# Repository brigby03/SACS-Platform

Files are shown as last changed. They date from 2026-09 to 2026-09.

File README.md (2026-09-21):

# SACS — Spacecraft Attitude Control Simulator

SACS is a single-axis, nearly frictionless spacecraft attitude-control testbed developed during Cal Poly's 2024 Summer Undergraduate Research Program (SURP). The platform rotates about its vertical $z$-axis on an air spindle and uses paired cold-gas thrusters to perform yaw maneuvers.

This repository contains the embedded control software and MATLAB/Simulink models used to simulate, command, and validate the platform.

> SACS is the original **single-axis SURP platform**. It is distinct from SADS, the three-axis spherical-air-bearing platform.

## Project goals

SACS was developed to:

- Create a low-complexity, low-friction physical analog of single-axis spacecraft rotation.
- Implement closed-loop yaw control using cold-gas thrusters.
- Compare predicted MATLAB/Simulink behavior with experimental results.
- Provide a testbed for control-law tuning and pulse-modulated actuator logic.

## System overview

The platform is built on an aluminum-extrusion frame supported by a porous-carbon air spindle. A compressed-gas supply feeds solenoid valves connected to opposing nozzle pairs. The nozzles are mounted at a moment arm from the center of rotation so that each pair produces positive or negative torque about the $z$-axis.

A BNO085 IMU measures platform yaw and angular rate. The embedded controller compares these measurements with the target state, calculates a desired torque using a PD control law, and converts the continuous command into discrete thruster firings.

```mermaid
flowchart TD
    TARGET["Target yaw and yaw rate"] --> PD["PD controller"]
    IMU["BNO085 yaw and gyro-Z"] --> PD
    PD --> LIMIT["Torque limit and thrust conversion"]
    LIMIT --> FILTER["First-order filter"]
    FILTER --> RELAY["Schmitt-trigger logic"]
    RELAY --> VALVES["Solenoid valves and cold-gas thrusters"]
    VALVES --> PLATFORM["Single-axis air-spindle platform"]
    PLATFORM --> IMU
```

## Control system

### PD attitude controller

The controller uses yaw-angle error and yaw-rate error:

$$
u = K_p(\theta_d-\theta) + K_d(\dot{\theta}_d-\dot{\theta}),
$$

where $u$ is the requested control torque. The gains can be selected from the desired natural frequency $\omega_n$, damping ratio $\zeta$, and estimated platform inertia $I_{zz}$:

$$
K_p = I_{zz}\omega_n^2,
\qquad
K_d = 2\zeta\omega_n I_{zz}.
$$

The requested torque is limited to the torque available from the thrusters and converted into the equivalent force required from each nozzle.

### Thruster modulation

Because the solenoid valves are on/off actuators, they cannot directly produce the continuous thrust requested by the PD controller. The embedded software therefore applies:

1. A first-order filter to the magnitude of the desired thrust.
2. A Schmitt trigger with separate on and off thresholds to provide hysteresis.
3. Sign logic to select the positive- or negative-torque thruster pair.

This PWPF-style approach reduces rapid valve switching while approximating a continuous control command with discrete pulses. This reduces fuel use while maintaining pointing within predefined thresholds.

### Operator controls

An IR remote is used to:

- Enable or disable closed-loop thruster firing [Power Button].
- Increment or decrement $K_p$ and $K_d$ [Volume +/-].
- Adjust the target yaw angle [see code].
- Adjust the target yaw rate [see code].

## Hardware represented by the software

| Component | Function |
| --- | --- |
| Single-axis air spindle | Provides nearly frictionless rotation about the vertical axis |
| Aluminum-extrusion platform | Supports the avionics, gas system, and thruster moment arms |
| Compressed-gas supply | Supplies the cold-gas propulsion system |
| Opposing nozzle pairs | Apply positive or negative yaw torque |
| Solenoid valves | Switch the thrusters on and off |
| BNO085 IMU | Measures yaw angle and angular velocity about $z$ |
| Embedded controller | Runs the feedback and thruster-modulation logic |
| IR receiver and remote | Enables the system and supports live tuning |

## Repository contents

| File | Description |
| --- | --- |
| `SACS_CS_1.3.ino` | Embedded PD controller, BNO085 interface, IR-remote input, filtering, and Schmitt-trigger thruster logic |
| `ControlledMotion.slx` | Simulink model of the closed-loop platform dynamics and pulsed-thruster controller |
| `ControlledMotionScript.m` | Defines controlled-motion parameters, runs the model, and plots attitude, body rate, and torque |
| `TorqueFreeMotion.slx` | Simulink model of rotational motion used to evaluate the platform dynamics |
| `TorqueFreeMotionScript.m` | Defines the inertia, applied torque, and initial conditions for the torque-free-motion model |

## Software requirements

### Embedded controller

- Arduino IDE or a compatible build environment
- [SparkFun BNO080/BNO085 Arduino Library](https://github.com/sparkfun/SparkFun_BNO080_Arduino_Library)
- [Arduino-IRremote](https://github.com/Arduino-IRremote/Arduino-IRremote)

The current sketch expects:

- BNO085 I²C address: `0x4A`
- I²C clock: `400 kHz`
- IMU update period: `50 ms`
- Positive- and negative-torque solenoid outputs: pins `3` and `4`
- IR receiver input: pin `15`
- Serial baud rate: `115200`

Confirm the target board, pin mapping, valve-driver polarity, and electrical interface before uploading the sketch.

### Simulation

- MATLAB
- Simulink
- Stateflow

The models were saved using MATLAB/Simulink R2024a. Compatibility with earlier releases is not guaranteed.

## Running the simulations

Place each script in the same directory as its corresponding Simulink model.

### Controlled motion

Open MATLAB in the repository directory and run:

```matlab
ControlledMotionScript
```

The script sets the inertia, initial attitude and body rate, controller gains, Schmitt-trigger thresholds, thruster torque, and simulation duration. It then runs `ControlledMotion.slx` and plots:

- Yaw angle versus time
- Angular velocity versus time
- Desired and commanded torque versus time

### Rotational dynamics

Run:

```matlab
TorqueFreeMotionScript
```

This initializes the inertia matrix, applied torque, initial angular velocity, and simulation duration before running `TorqueFreeMotion.slx`.

## Running the physical platform via cold gas thrusters.

1. Place the platform onto a flat and level surface.
2. Place the paintball canister into the sleeve in the center of the platform and attach it's output hose to the thruster manifold. Be sure not to open the valve on the paintball canister until immediately prior to running a control test.
3. Ensure that the air compressor is powered and connected to the inlet of the Air Spindle, and flip the lever to turn on the air compressor. This will allow the platform to freely spin. The air compressor will fill to ~120psi and then shut off until it falls to ~90psi, and then refill until powered off.
4. Verify that the platform is balanced and free to rotate without cable interference. In the somewhat likely event of an unbalanced platform, you can shim the four corners with thin microfiber towels and check  the proper orientation of the platform with a levels.
5. Open the valve of the paintball canister to allow pressurized air into the thruster manifold.
6. Press the IR-remote power button to enable once the paintball canister's valve has been opened and the platform is freely spinning. The power button can be used to enable/disable control at any time for convenience of testing/demonstration.
7. Once the test is complete, disable control via the power button on the IR-remote to stop the valves from opening.
8. Once the platform is settled to a stop, close the valve on the paintball canister, and then re-enable thruster control one last time in order to purge the lines of any remaining pressurized air.
9. Once the lines have been purged, the paintball canister can be removed and the platform can be stowed.

## Experimental validation

The Simulink model was used to predict the controlled yaw response and compare it with the physical platform. Repeated large-angle maneuver tests settled in roughly **14–15 seconds**, closely matching the simulated response. Differences between the model and experiment were attributed primarily to uncertainty in delivered thrust and unmodeled friction.

## Safety

This project operates pressurized gas, electrically actuated valves, and a freely rotating structure.

- Wear eye protection during pressurized testing.
- Keep people and loose objects outside the platform's swept area.
- Never provide power to the valves while hands or tools are near a nozzle or moving structure.
- Always keep the paintball canister's valve closed until undergoing pressurized testing to avoid unexpected mishaps with the valves.
- Depressurize the system before changing pneumatic connections.
- Provide accessible electrical and pneumatic emergency shutoffs.

## Academic context

SACS was originally developed by **Bricen Rigby** through the 2024 Summer Undergraduate Research Program in the Aerospace Engineering Department at California Polytechnic State University, San Luis Obispo, under the guidance of **Professor Eric Mehiel**. It has since been used in multiple theses related to spacecraft attitude control simulation and testing for its utility in sensor, actuator, and control system validation.

## License

No license has been selected. Until a license is added, the source is not automatically licensed for reuse, modification, or redistribution.

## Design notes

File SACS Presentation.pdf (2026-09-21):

# Spacecraft Attitude

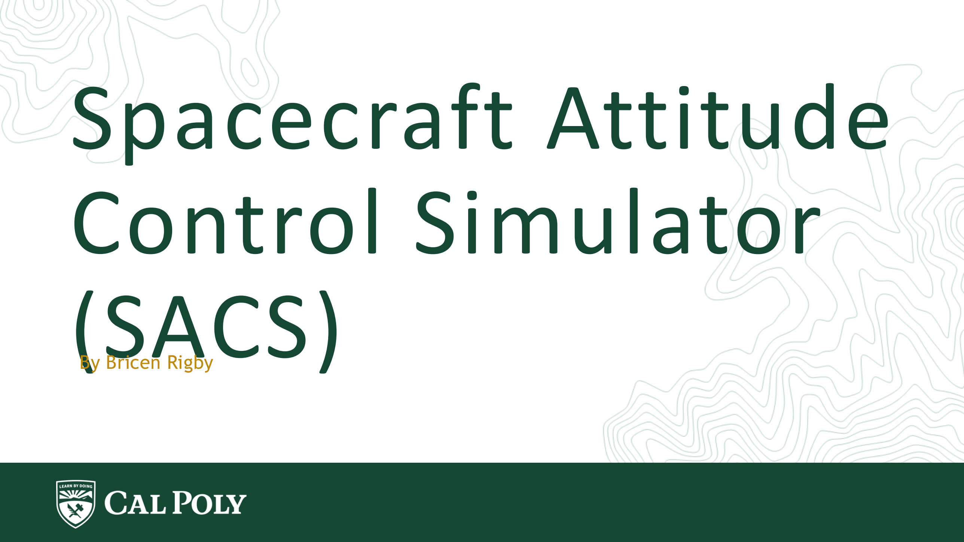
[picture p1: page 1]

# Control Simulator

(SACS) By Bricen Rigby

# Project Overview

## Objective:

## Develop a single-axis attitude control simulator to replicate the frictionless environment of space and test cold gas thruster control

schemes.

## Key Goals:

## - Validate control logic via real-time testing

## - Compare observed vs. simulated dynamics

## - Improve fidelity and efficiency of spacecraft simulator testbeds

# Hardware & Assembly

## Key Components:

- Air Spindle: Provides near-frictionless rotation using porous carbon
- Cold Gas Thrusters: Controlled via solenoid valves & moment arms
- Frame: Constructed from aluminum extrusion for modularity
- Paintball Bottle: Supplies compressed air

## Fusion 360 modeling:

- Used to determine mass properties & optimize nozzle arm placement

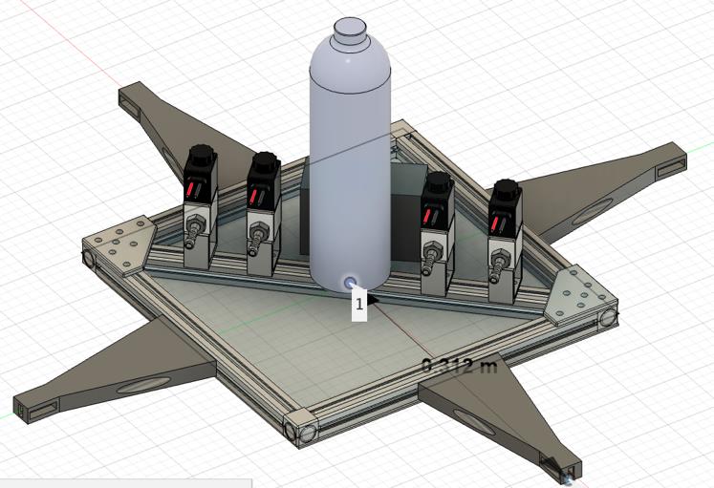
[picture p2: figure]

Figure 1. SACS Platform as modeled in Fusion 360

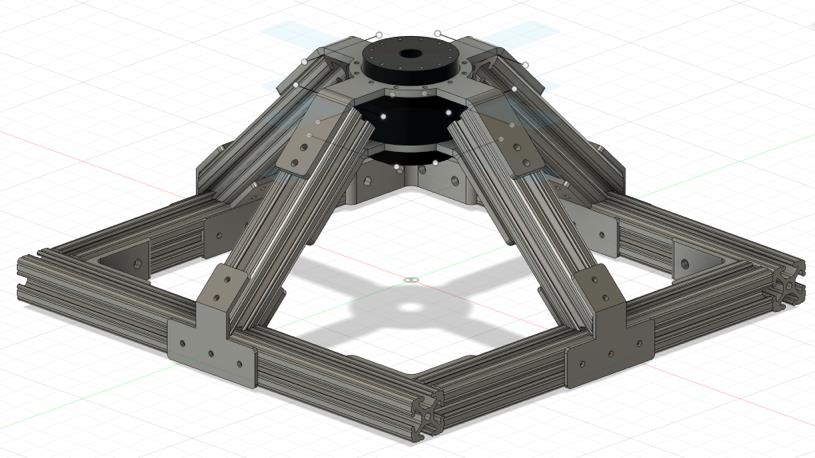
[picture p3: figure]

Figure 2. Base for the SACS Platform, containing the air spindle

# Control System & Simulation

## Hardware Logic:

- Teensy microcontroller + MOSFETs to actuate solenoids
- Diodes for back-EMF protection
- Custom PCB for robustness over breadboarding

## Simulink Control Model:

- Integrates equations of motion
- PD control (Kp/Kd gains) + Schmitt Trigger logic
- Simulates torque command and valve switching behavior

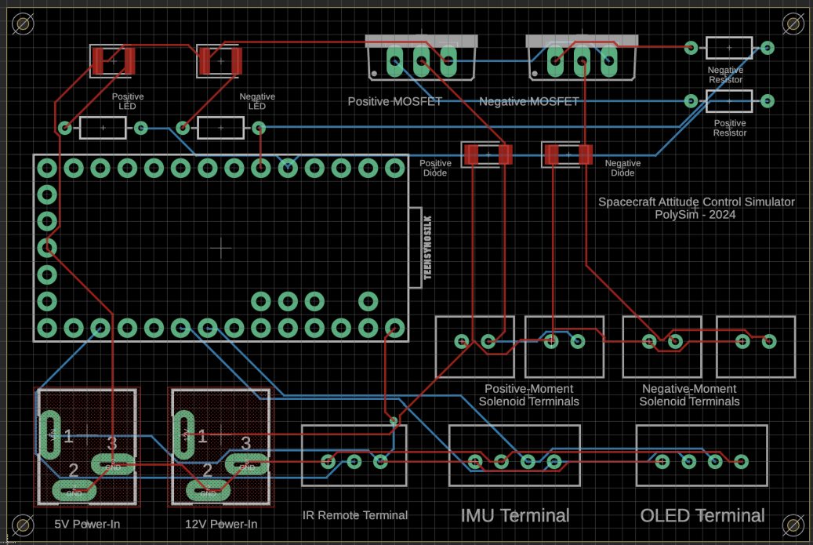
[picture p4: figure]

Figure 3. Custom Printed Circuit Board Design in Fusion 360

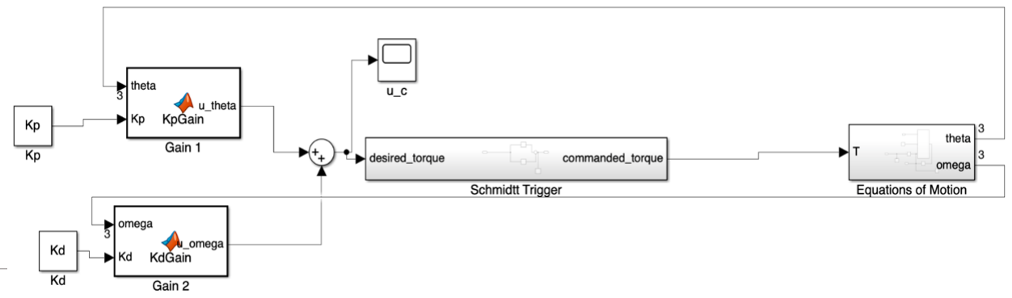
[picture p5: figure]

Figure 4. Simulink Model of the SACS Platform

# Results & Validation

## Implication:

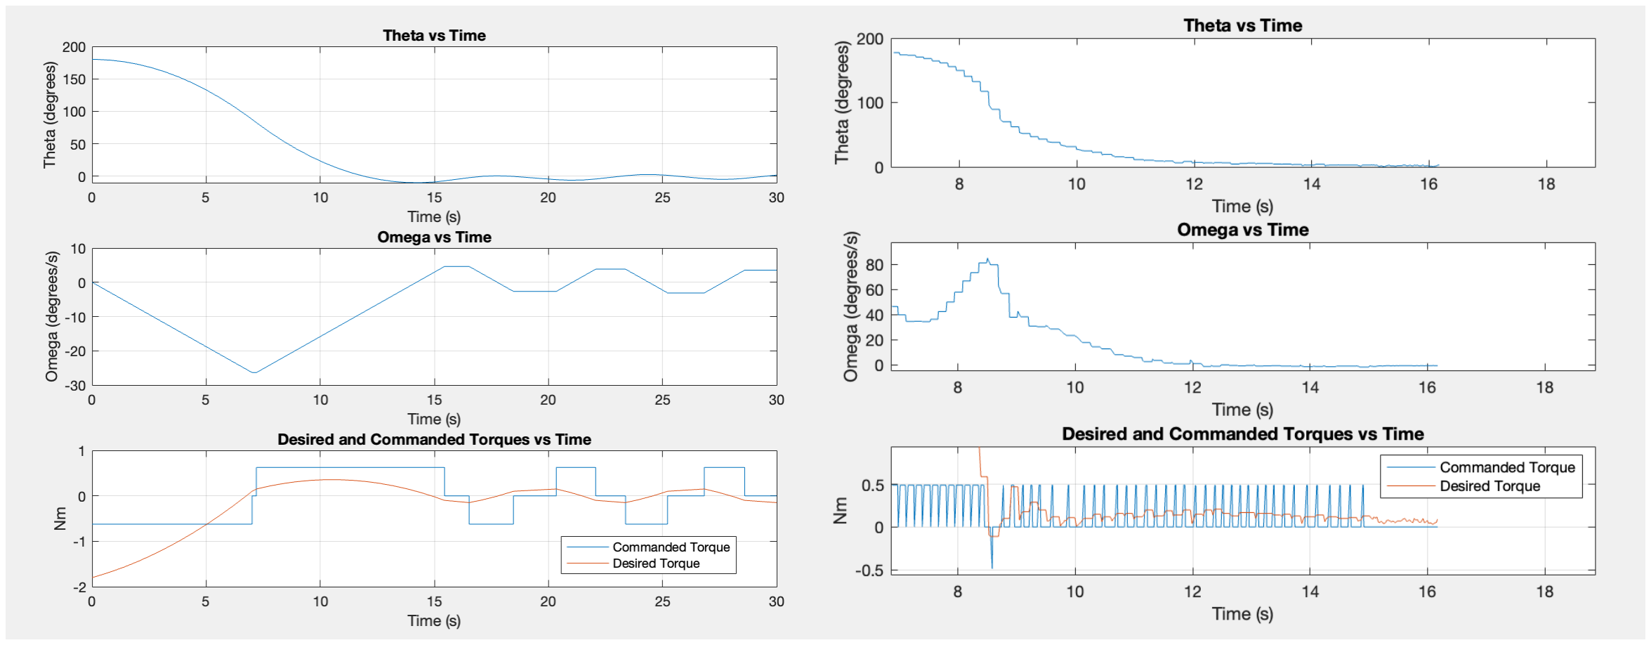
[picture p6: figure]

Platform effectively replicates low-friction rotational dynamics and allows for real-world control scheme testing.

## Settling Time Comparison:

- Simulated: 14 seconds
- Observed: 13 seconds
- Error: ~7% (likely from
underestimating actual
thrust)
Simulated Data | Observed Data

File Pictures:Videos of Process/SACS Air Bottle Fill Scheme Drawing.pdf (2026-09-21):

## $50 High Pressure Hand Pump - Amazon

## Solenoid Valves w/ two ¼” NPT Barbed Connectors

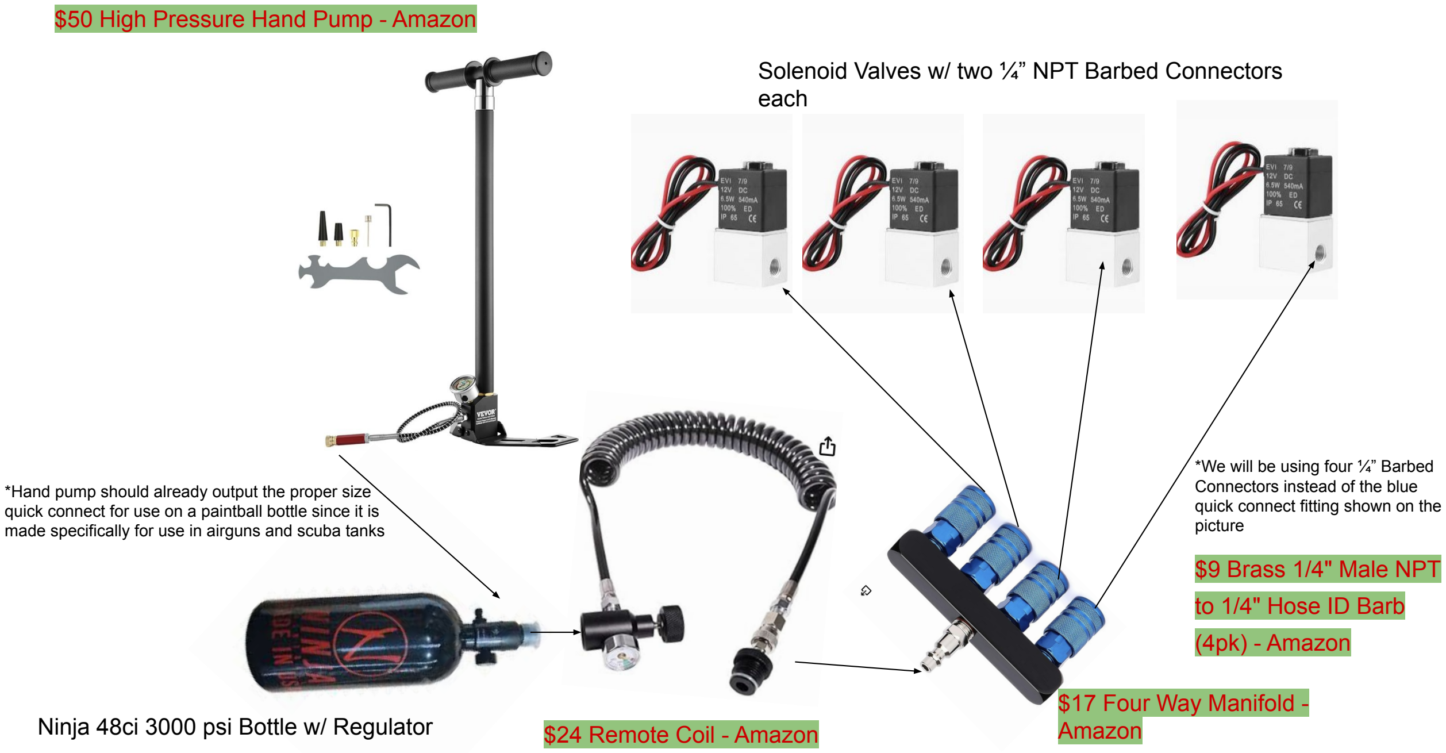
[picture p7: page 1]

Ninja 48ci 3000 psi Bottle w/ Regulator | $24 Remote Coil - Amazon

## $17 Four Way Manifold -Amazon

## each

*Hand pump should already output the proper size quick connect for use on a paintball bottle since it is made specifically for use in airguns and scuba tanks

*We will be using four ¼” Barbed Connectors instead of the blue quick connect fitting shown on the picture

## $9 Brass 1/4" Male NPT

## to 1/4" Hose ID Barb

## (4pk) - Amazon

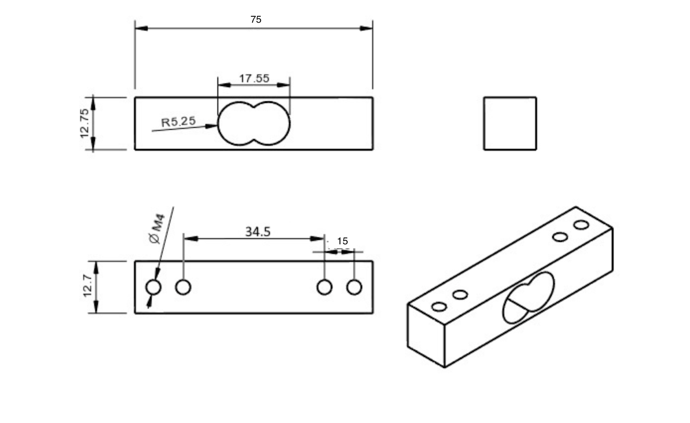
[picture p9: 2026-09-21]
3D Models/5kgLoadCellDimensions.png

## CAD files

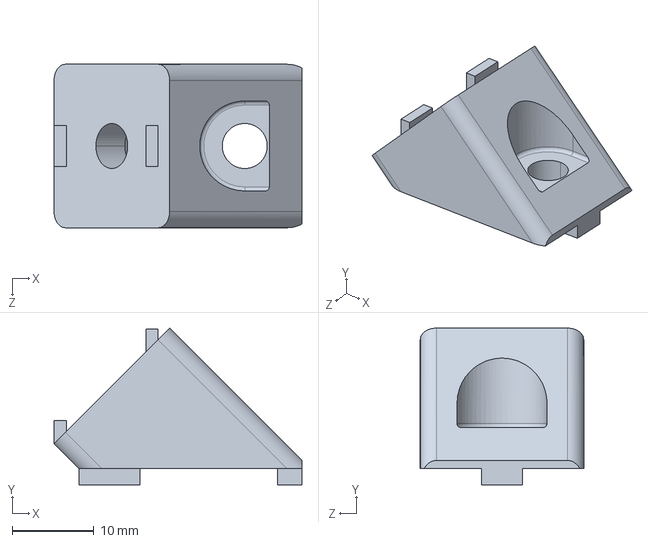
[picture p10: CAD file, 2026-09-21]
3D Models/20mm90degBracket.STEP
30.3 x 19.2 x 20.0 mm

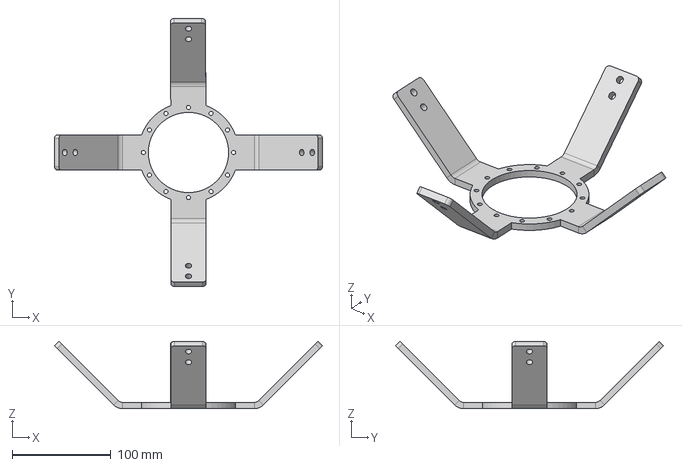
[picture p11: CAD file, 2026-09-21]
3D Models/Air Spindle Related/Air Spindle Mounting Bracket - Lower.step
271.5 x 271.5 x 68.1 mm

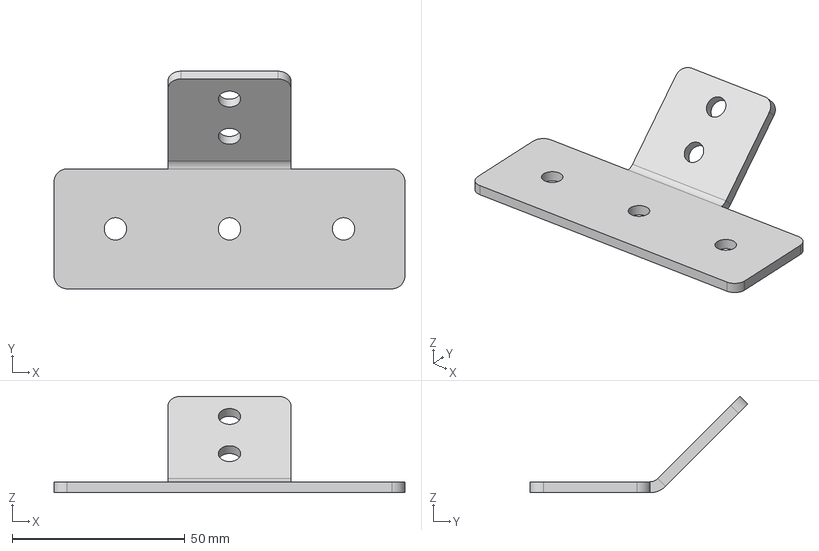
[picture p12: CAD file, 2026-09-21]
3D Models/Air Spindle Related/Sheet Metal Inner Mounting Bracket.step
101.6 x 63.0 x 27.9 mm

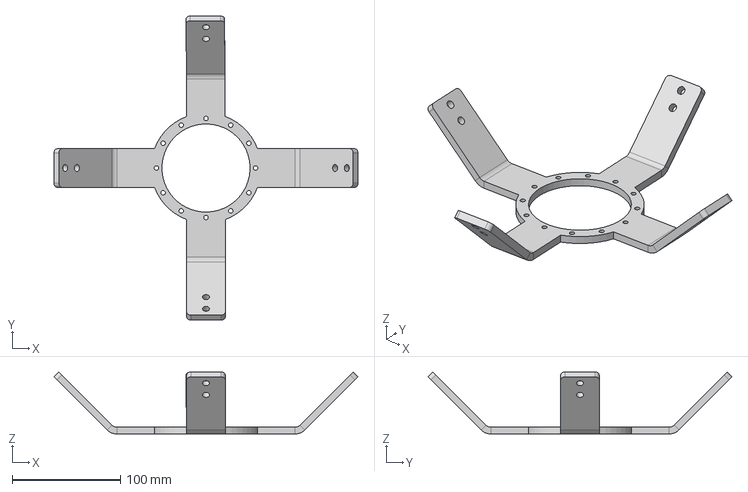
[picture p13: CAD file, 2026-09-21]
3D Models/Air Spindle Related/Sheet Metal Upper Mounting Bracket.step
280.5 x 280.5 x 57.2 mm

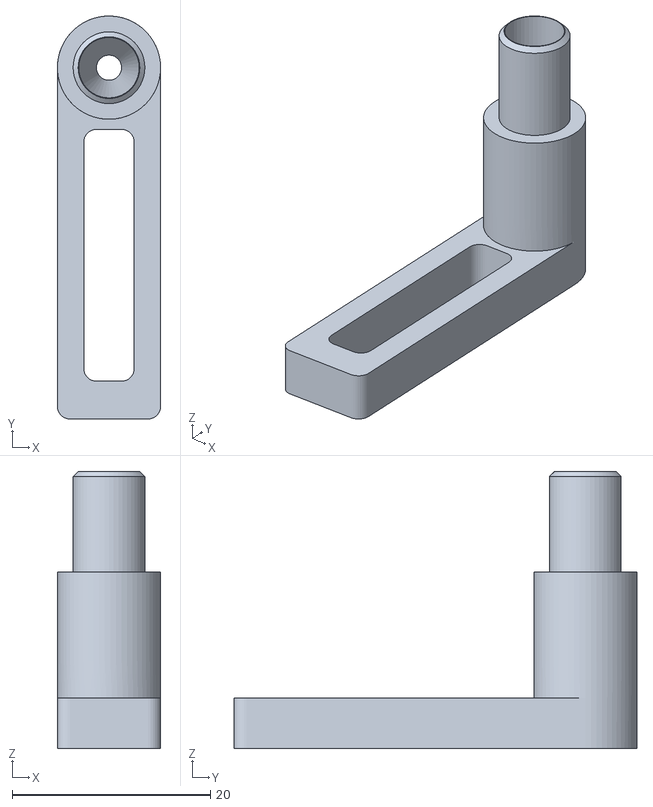
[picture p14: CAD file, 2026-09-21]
3D Models/Converging Nozzle.stl
10.4 x 40.6 x 27.9

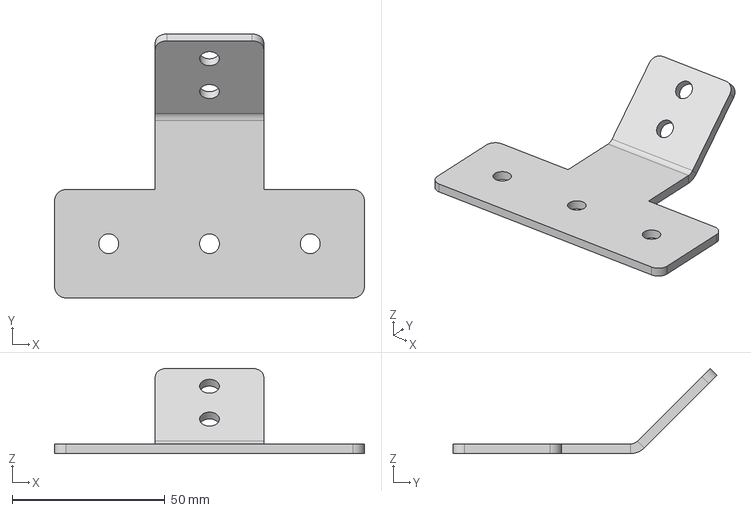
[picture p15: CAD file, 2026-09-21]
3D Models/Air Spindle Related/Sheet Metal Outer Mounting Bracket.step
101.6 x 86.5 x 27.9 mm

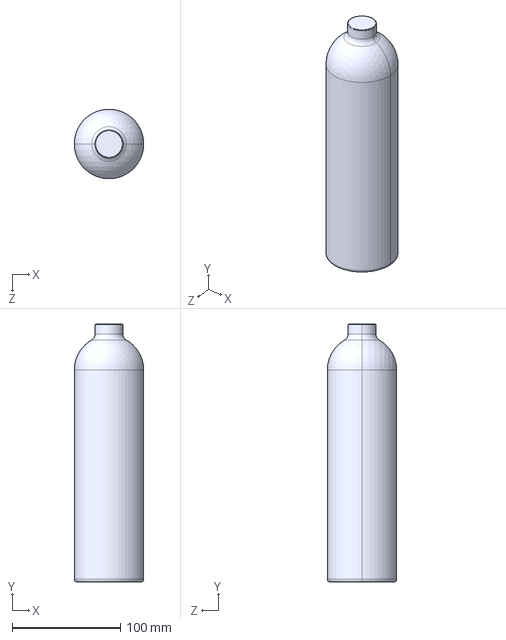
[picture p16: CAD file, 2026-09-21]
3D Models/Tippman12ozBottle.STEP
64.1 x 238.1 x 64.1 mm

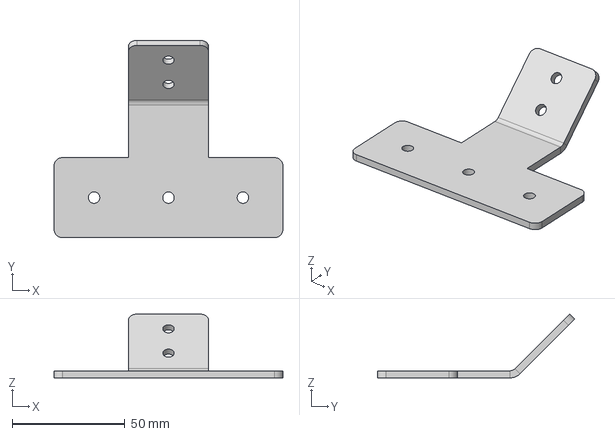
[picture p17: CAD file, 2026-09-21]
3D Models/Sheet Metal Outer Mounting Bracket.step
101.6 x 87.6 x 28.4 mm

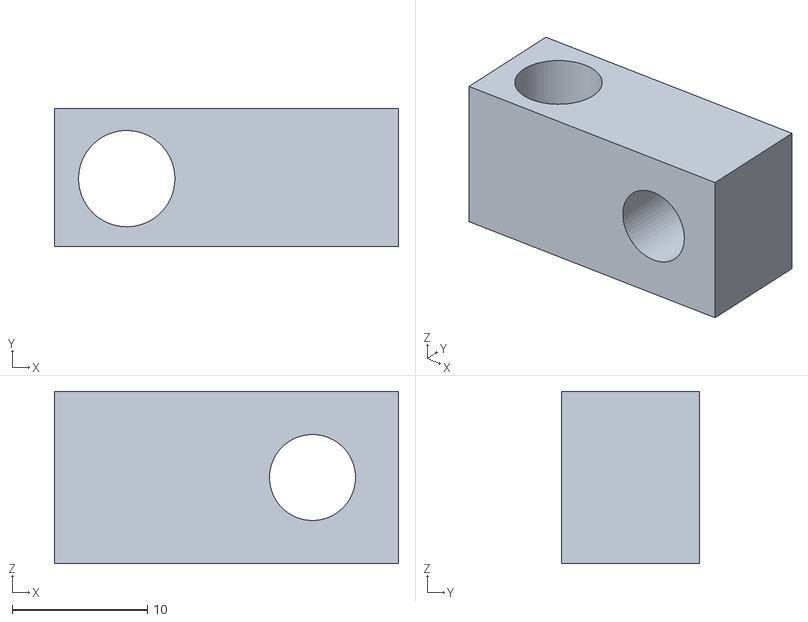
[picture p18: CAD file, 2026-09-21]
3D Models/Turntable_to_Loadcell_brackeet.stl
25.4 x 10.2 x 12.7

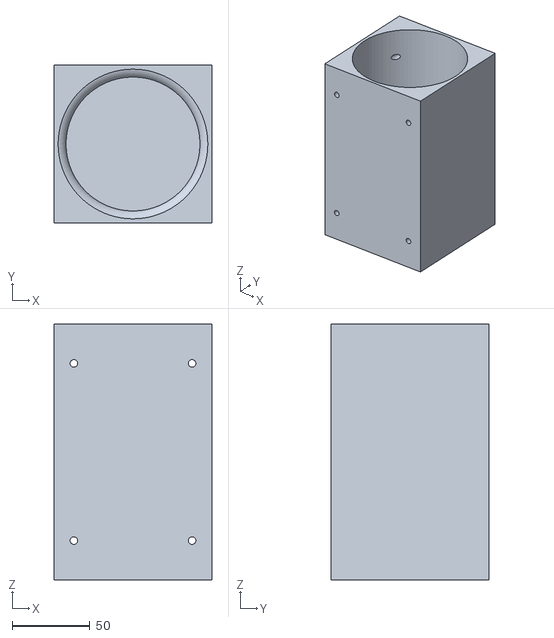
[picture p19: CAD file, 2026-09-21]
3D Models/Sleeve for Air Bottle.stl
101.6 x 101.6 x 165.1

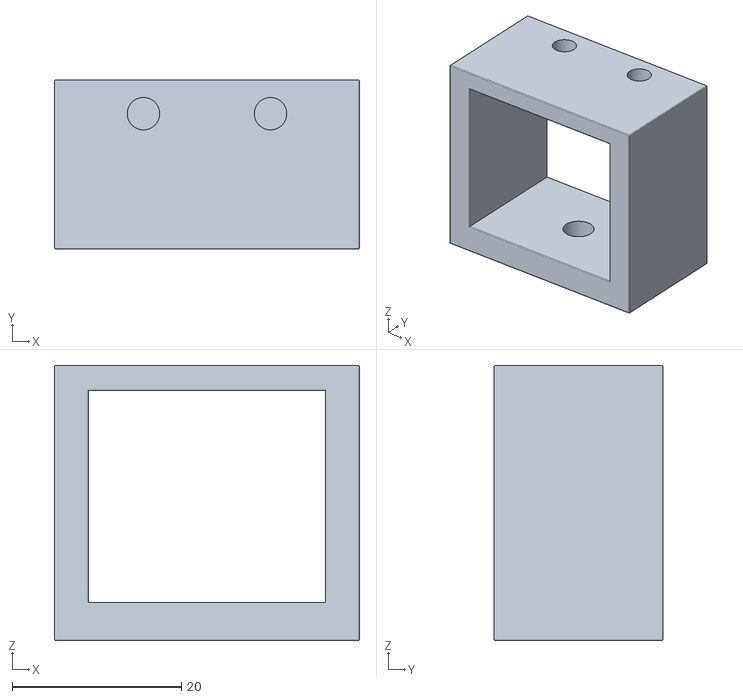
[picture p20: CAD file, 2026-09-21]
3D Models/Solenoid Mounting Bracket V2.stl
36.0 x 20.0 x 32.5

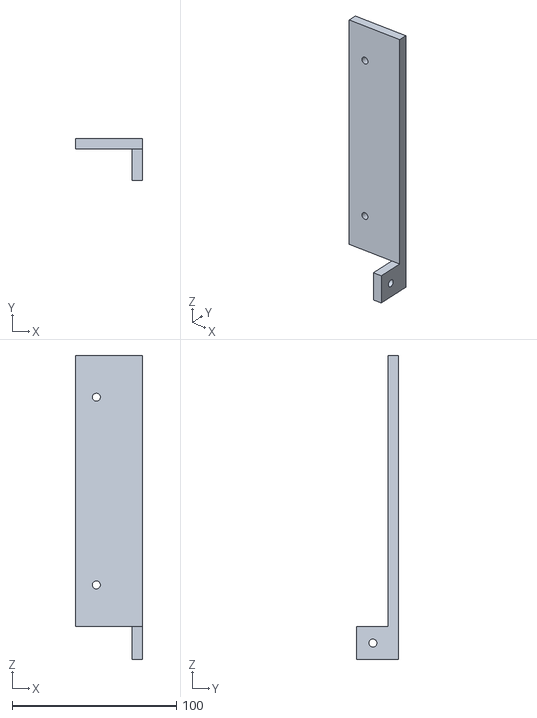
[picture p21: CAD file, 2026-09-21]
3D Models/Sleeve Mounting Bracket (Left).stl
40.8 x 25.4 x 185.1

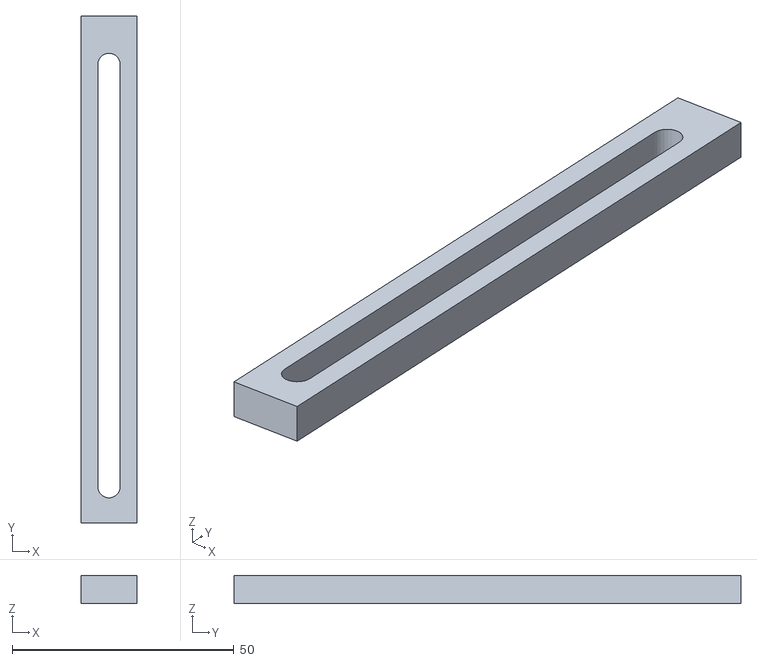
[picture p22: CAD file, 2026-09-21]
3D Models/Load Cell Test Bracket.stl
12.7 x 114.3 x 6.35

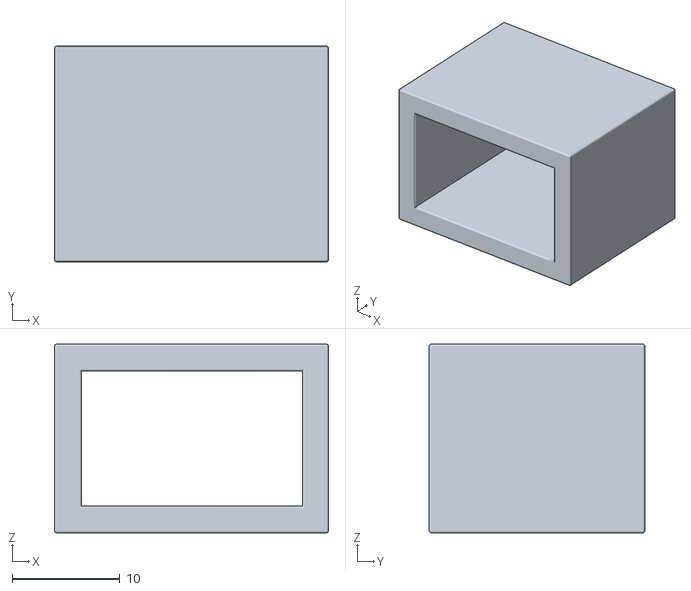
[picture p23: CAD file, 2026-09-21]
3D Models/Solenoid Mounting Bracket.stl
25.4 x 20.0 x 17.5

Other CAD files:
3D Models/Load Cell Calibration Stand.stl
3D Models/Nozzle Moment Arm.stl
3D Models/Load Cell Mount Bracket #2.stl
3D Models/Air Manifold Bracket.stl
3D Models/20mmExtrudedRail.STEP
3D Models/20mmNut+Screw.STEP
3D Models/5537T651_T-Slotted Framing.STEP
3D Models/5537T935_T-Slotted Framing.STEP
3D Models/SACS Assembly V2.f3d
3D Models/SOLENOID VALVE, 1_4 NPT, 12VDC.step
3D Models/Sleeve Mounting Bracket (Right).stl
PCB/SACS PCB 3D Model.f3d

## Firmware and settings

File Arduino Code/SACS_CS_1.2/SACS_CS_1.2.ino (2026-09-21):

// SACS 1.20 
// PWM Thruster Control Logic for 1-Axis stabilization

//Include Libraries
#include <Wire.h>
#include "SparkFun_BNO080_Arduino_Library.h" // Click here to get the library: http://librarymanager/All#SparkFun_BNO080
#include <IRremote.hpp>

// Pin Definitions
const int solenoid1_pin = 3;
const int solenoid2_pin = 4;
const int remote_pin = 15;
#define IR_RECEIVE_PIN remote_pin

// Declare State Variables
float theta; // [deg]
float theta_dot; // [deg]

// Define Error Variables and Reference Targets
float target_theta = 0, target_theta_dot = 0; // [deg] *SET THIS VARIABLE FOR DESIRED POSITION AND VELOCITY*
float theta_error; float theta_dot_error; // [rad], [rad/s]

// Define Gains
float moment_of_inertia = 0.2; // [kg m^2]
float natural_frequency = 3; // [rad/s]
float damping_ratio = 0.3; // 0-1: Underdamped, 1: Critically Damped, 1+: Overdamped
float Kp = moment_of_inertia * natural_frequency * natural_frequency;
float Kd = 2 * damping_ratio * moment_of_inertia * natural_frequency; 
float gainIncrement = 0.01; //IR Remote stuff

// Thrust Characteristics based on 100 Psi Measurements
float thrust_output = 3.125; //thrust produced by a single nozzle [newtons]
float nozzle_moment_distance = .312; //perpindicular distance of a nozzle from the center-of-rotation of the platform [meters]
float control_torque = 2 * thrust_output * nozzle_moment_distance; // torque applied to the platform whenever a pair of thrusters is on [Nm]

// Declare Thrust Control Variables
float u = 0; //control input[Nm]
float uCommanded; //signed, bounded value commanded by controller to the thrusters [Nm]
float desired_thrust; // useful in commanding solenoid valves [newtons]
int pwm_period = 100; // [milliseconds] making pwm_period smaller should increase the performance of the system up to the limit of the solenoid valve
float throttle_ratio; // [Range from 0-1] useful in commanding pwm: Represents the portion of the pwm_period spent with the thrusters on
unsigned long openMillis; // [milliseconds] useful in pwm timing control
unsigned long closeMillis; // [milliseconds] useful in pwm timing control
unsigned long timer; // [milliseconds] useful in pwm timing control. Made to be very large because once this fills up, the program bricks. This will run for 50 days
bool hysteresis_number; // true represents theta is positive,  false represents theta is negative. Useful variable when writing schmitt trigger logic
bool OnOffSwitch = false; // Define the boolean for On/Off state controlled by the IR Remote

// Define Dead-Band Parameters
float deltaOn = 0.15; //started this value at 0.2, but it would get close to zero and then slow down to the point that it couldn't overcome friction so it wouldn't quite reach zero
float deltaOff= 0.05; //deltaOff MUST BE SMALLER than deltaOn

// Setup for IMU
BNO080 myIMU;


//Setup for IR Remote
const uint32_t powerHex = 0xBA45FF00;
const uint32_t volUpHex = 0xB946FF00;
const uint32_t funcHex = 0xB847FF00;
const uint32_t rewindHex = 0xBB44FF00;
const uint32_t playPauseHex = 0xBF40FF00;
const uint32_t fastForwardHex = 0xBC43FF00;
const uint32_t downHex = 0xF807FF00;
const uint32_t volDownHex = 0xEA15FF00;
const uint32_t upHex = 0xF609FF00;
const uint32_t zeroHex = 0xE916FF00;
const uint32_t EQHex = 0xE619FF00;
const uint32_t STHex = 0xF20DFF00;
const uint32_t oneHex = 0xF30CFF00;
const uint32_t twoHex = 0xE718FF00;
const uint32_t threeHex = 0xA15EFF00;
const uint32_t fourHex = 0xF708FF00;
const uint32_t fiveHex = 0xE31CFF00;
const uint32_t sixHex = 0xA55AFF00;
const uint32_t sevenHex = 0xBD42FF00;
const uint32_t eightHex = 0xAD52FF00;
const uint32_t nineHex = 0xB54AFF00;




void setup() {
  Serial.begin(115200);
  Wire.begin();
  Wire.setClock(400000);
  delay(2000);
  Serial.println("Serial Begun");
  
  //Initialize the BNO085 IMU at address 0x4A, if not send error message
  if (!myIMU.begin(0x4A)) {
      while (1) {
          Serial.println(F("BNO085 not detected at default I2C address. Check your jumpers and the hookup guide. Freezing..."));
          delay(5000);
      }
  }
  else Serial.println("MPU Connection Successful!"); delay(1000);
  myIMU.enableRotationVector(50); //Send data update every 50ms
  myIMU.enableGyro(50); //Send data update every 50ms

  //Initialize the IR Remote
  IrReceiver.begin(IR_RECEIVE_PIN, ENABLE_LED_FEEDBACK);

  // Set pin modes
  pinMode(solenoid1_pin, OUTPUT);
  pinMode(solenoid2_pin, OUTPUT);
  pinMode(remote_pin, INPUT);

  Serial.println();
  Serial.println("Starting..."); 
  Serial.println();
  Serial.println();

  //Find initial Schmitt Number for Hysteresis
  updateIMUState();
  if(theta > 0) {hysteresis_number = true;} //this line assumes that initially, theta_dot ~= 0;
  else {hysteresis_number = false;} //this line assumes that initially, theta_dot ~= 0;
}






void loop() {
  
  updateIMUState();
  updateRemote();

  // Uncomment this for troubleshooting with the serial monitor
  
  if(OnOffSwitch == true)
  {
    Serial.print("Theta: ");Serial.print(theta);Serial.print(" \tTheta Dot: ");
    Serial.print(theta_dot);Serial.print(" \tDesired Thrust: ");
    Serial.print(desired_thrust); Serial.print(" \tCommanded Moment: ");
    Serial.print(u); Serial.print(" \tTime: ");
    Serial.println(millis()/1000);
  }
  else
  {
    Serial.println("Waiting to be activated...");
    Serial.print("Theta: ");Serial.print(theta);Serial.print(" \tTheta Dot: ");
    Serial.print(theta_dot);Serial.print(" \tDesired Thrust: ");
    Serial.print(desired_thrust); Serial.print(" \tCommanded Moment: ");
    Serial.print(u); Serial.print(" \tTime: ");
    Serial.println(millis()/1000);
    updateRemote();
  }
  

  desired_thrust = calculateDesiredThrust(theta, target_theta, theta_dot, target_theta_dot, Kp, Kd, control_torque); //desired, signed torque for an individual thruster

  updateIMUState();


  // command the thrusters to actuate ONLY if the schmitt value is not within dead band
  if (hysteresis_number == true && OnOffSwitch == true)
  {
    if (desired_thrust > deltaOff) fireThrusters(desired_thrust);
    else if(desired_thrust < -deltaOn) {fireThrusters(desired_thrust); hysteresis_number = false;}
  }
  else if(hysteresis_number == false && OnOffSwitch == true)
  {
    if (desired_thrust < -deltaOff) fireThrusters(desired_thrust);
    else if(desired_thrust > deltaOn) {fireThrusters(desired_thrust); hysteresis_number = true;}
  }
  // notice if schmittNumber == 0, the thrusters are never commanded to fire.

}



// functions:

float calculateDesiredThrust(float theta, float target_theta, float theta_dot, float target_theta_dot, float Kp, float Kd, float control_torque)
{
  // Calculate Control Input through PD control law
  theta_error = PI*(target_theta - theta)/180; // [rad]
  theta_dot_error = PI*(target_theta_dot - theta_dot)/180; // [rad/s]
  u = Kp*theta_error+Kd*theta_dot_error; // [Nm]

  updateIMUState();

  // if the desired control torque is greater than the actual control torque, constrain the signed commanded torque to be equal to control_torque
  if(abs(u)>control_torque){ 
    if(u>0) uCommanded = control_torque;
    else uCommanded = -control_torque;
  } 
  else uCommanded = u;

  desired_thrust = uCommanded/nozzle_moment_distance/2; // represents the ideal output of a single thruster if we could throttle it (but we can't)

  return desired_thrust; // [newtons]
}

void fireThrusters(float desired_thrust) //applies pwm control logic and commands MOSFET gates for the solenoid valves
{
  throttle_ratio = abs(desired_thrust / thrust_output); // represents how much of the time of the 100 ms the thrusters will be on in order to match the desired thrust
  // Notice that the throttle_ratio is always going to be somewhere from zero to one
  openMillis = pwm_period * throttle_ratio; // openMillis represents the amount of time the valves should stay open in milliseconds
  //Serial.print("open_Millis = "); Serial.println(openMillis);
  closeMillis = pwm_period * (1-throttle_ratio); // closeMillis represents the amount of time the valves should stay closed in milliseconds
  //Serial.print("close_Millis = "); Serial.println(closeMillis);
  updateIMUState();
  if(desired_thrust>0) // i.e. fire the positive-spin thrusters
  {
    //start by setting the two unused thrusters to LOW
    digitalWrite(solenoid1_pin,LOW);

    //implement pwm control logic for one period of thrusting
    digitalWrite(solenoid2_pin, HIGH);
    timer = millis();
    while(millis() - timer < openMillis)
    {
      updateIMUState();
      /* //Uncomment for Serial Troubleshooting
      Serial.print("Theta: ");Serial.print(theta);Serial.print(" \tTheta Dot: ");
      Serial.print(theta_dot);Serial.print(" \tDesired Moment: ");
      Serial.print(desired_Thrust); Serial.print(" \tCommanded Thrust: ");
      Serial.print(u); Serial.print("[Nm] \tTime: ");
      Serial.println(millis()/1000);
      */
    }


    digitalWrite(solenoid2_pin, LOW);
    timer = millis();
    while(millis() - timer < closeMillis)
    {
      updateIMUState();
      /* //Uncomment for Serial Troubleshooting
      Serial.print("Theta: ");Serial.print(theta);Serial.print(" \tTheta Dot: ");
      Serial.print(theta_dot);Serial.print(" \tDesired Thrust: ");
      Serial.print(desired_thrust); Serial.print(" \tCommanded Moment: ");
      Serial.print(u); Serial.print("[Nm] \tTime: ");
      Serial.println(millis()/1000);
      */
    }
  }
  else // i.e. fire the negative-spin thrusters
  {
    //start by setting the two unused thrusters to LOW
    digitalWrite(solenoid2_pin,LOW);

    //implement pwm control logic for one period of thrusting
    digitalWrite(solenoid1_pin, HIGH);
    timer = millis();
    while(millis() - timer < openMillis)
    {
      updateIMUState();
      /* //Uncomment for Serial Troubleshooting
      Serial.print("Theta: ");Serial.print(theta);Serial.print(" \tTheta Dot: ");
      Serial.print(theta_dot);Serial.print(" \tDesired Thrust: ");
      Serial.print(desired_thrust); Serial.print(" \tCommanded Moment: ");
      Serial.print(u); Serial.print("[Nm] \tTime: ");
      Serial.println(millis()/1000);
      */
    }

    digitalWrite(solenoid1_pin, LOW);
    timer = millis();
    while(millis() - timer < closeMillis)
    {
      updateIMUState();
      /* //Uncomment for Serial Troubleshooting
      Serial.print("Theta: ");Serial.print(theta);Serial.print(" \tTheta Dot: ");
      Serial.print(theta_dot);Serial.print(" \tDesired Thrust: ");
      Serial.print(desired_thrust); Serial.print(" \tCommanded Moment: ");
      Serial.print(u); Serial.print("[Nm] \tTime: ");
      Serial.print(millis()/1000);
      */
    }
  }
}

void updateRemote()
{
  if (IrReceiver.decode()) {
    uint32_t receivedValue = IrReceiver.decodedIRData.decodedRawData;

    Serial.print("Received IR Code: 0x");
    Serial.println(receivedValue, HEX);

    if (receivedValue == powerHex) OnOffSwitch = !OnOffSwitch; Serial.println("Power Switched!");
    if (receivedValue == volUpHex) Kd += gainIncrement;
    if (receivedValue == volDownHex) Kd -= gainIncrement;
    if (receivedValue == upHex) Kp += gainIncrement;
    if (receivedValue == downHex) Kp -= gainIncrement;
    if (receivedValue == EQHex) target_theta -= 1;
    if (receivedValue == STHex) target_theta += 1;
    if (receivedValue == rewindHex) target_theta_dot -= 1;
    if (receivedValue == fastForwardHex) target_theta_dot += 1;

    IrReceiver.resume();  // Ready to receive the next value
  }
}

void updateIMUState()
{
  if (myIMU.dataAvailable() == true)
  {
    theta = myIMU.getYaw()/PI*180;
    theta_dot = myIMU.getGyroZ()/PI*180;
  }
  //Implement refresh of the OLED Screen
}

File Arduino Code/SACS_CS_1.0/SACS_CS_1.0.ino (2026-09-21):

//Include Libraries
#include "MPU9250.h"

// Thruster Control Pins
const int solenoid1_pin = 2;
const int solenoid2_pin = 3;

// Thruster and Platform Characteristics based on 100 Psi
float maximum_thrust = 1; //in newtons
float minimum_thrust = 0; //in newtons
float nozzle_moment_distance = .243; //perpindicular distance from COM in meters
float maximum_control_torque = 2 * maximum_thrust * nozzle_moment_distance;
float thrust_per_dutyCycle = 1; //in [Newtons per %], this is the conversion factor from desired thrust to actuated dutyCycle

// this variable represents the amount of time spent thrusting during each cycle in milliseconds
int pwm_period = 100; // making pwm_period smaller should increase the performance of the system up to the limit of the solenoid valve

float theta = 10;
float theta_dot = 10;

// Define Gains, values determined from parameter sweep in MATLAB
float Kp = 0.0159;
float Kd = 0.015;

float theta_error = 0, theta_dot_error = 0;
float target_theta = 0, target_theta_dot = 0; // SET THIS VARIABLE FOR DESIRED POSITION AND VELOCITY

float u;
float uCommanded;
float desired_thrust;
float throttle_ratio;
int openGap;
int closeGap;
unsigned long timer;

// Setup for IMU
MPU9250 mpu;




void setup() {
  Serial.begin(115200);
  Wire.begin();
  delay(2000);

  if (!mpu.setup(0x68)) { 
        while (1) {
            Serial.println("MPU connection failed. Please check your connection with `connection_check` example.");
            delay(5000);
        }
    }
  else Serial.println("MPU Connection Successful!");


  // Variable output window to begin:
  Serial.print("nozzle_moment_distance = "); Serial.println(nozzle_moment_distance);
  Serial.print("maximum_control_torque = "); Serial.println(maximum_control_torque);

  // Set pin modes
  pinMode(solenoid1_pin, OUTPUT);
  pinMode(solenoid2_pin, OUTPUT);
  //pinMode(solenoid3_pin, OUTPUT);  // uncomment this when using four-thruster setup
  //pinMode(solenoid4_pin, OUTPUT);  // uncomment this when using four-thruster setup

  Serial.println();
  Serial.println("Starting..."); 
  Serial.println();
  Serial.println();
}






void loop() {

  // Read Sensor data
  if (mpu.update()) {
        static uint32_t prev_ms = millis();
        if (millis() > prev_ms + 25) {
            updateState();
            prev_ms = millis();
        }
    }

  u = 0; // initialize variable for control torque

  // Calculate Control Input through PD control law
  theta_error = target_theta - theta;
  theta_dot_error = target_theta_dot - theta_dot;
  u = -Kp*theta_error+Kd*theta_dot_error; Serial.println(u);

  mpu.update();




  // contrain the commanded torque to be within the maximum_control_torque
  if(abs(u)>maximum_control_torque){ 
    if(u>0) uCommanded = maximum_control_torque; //change this to .35 if not working
    else uCommanded = -maximum_control_torque;
  } 
  else uCommanded = u;


  desired_thrust = uCommanded/nozzle_moment_distance/2; //equation based on platform setup: divide by 2 since there are 2 nozzles per couple


  mpu.update();
  // Command the thrusters to actuate the control input
  fireThrusters(desired_thrust);

  checkCalibrateIMU(); //check for a tare command

}







// functions:


void fireThrusters(float desired_thrust)
{
  throttle_ratio = abs((desired_thrust - minimum_thrust)/thrust_per_dutyCycle); // create x = (y-b)/m for thrust to duty cycle conversion. This represents the ideal case of b = 0, m = 1
  Serial.print("throttle_ratio = "); Serial.println(throttle_ratio);
  openGap = pwm_period * throttle_ratio; // openGap represents the amount of time the valves should stay open in milliseconds
  //Serial.print("open_gap = "); Serial.println(openGap);
  closeGap = pwm_period - openGap; // closeGap represents the amount of time the valves should stay closed in milliseconds
  //Serial.print("close_gap = "); Serial.println(closeGap);
  mpu.update();
  if(desired_thrust>0) // i.e. fire the negative-moment thrusters
  {
    //start by setting the two unused thrusters to LOW
    digitalWrite(solenoid2_pin,LOW);
    //digitalWrite(solenoid4_pin,LOW);  // uncomment this when using four-thruster setup

    //implement pwm control logic for one period of thrusting
    digitalWrite(solenoid1_pin, HIGH);
    //digitalWrite(solenoid3_pin, HIGH);  // uncomment this when using four-thruster setup
    timer = millis();
    while(millis() - timer < openGap)
    {
      mpu.update();
    }


    digitalWrite(solenoid1_pin, LOW);
    //digitalWrite(solenoid3_pin, LOW);  // uncomment this when using four-thruster setup
    timer = millis();
    while(millis() - timer < closeGap)
    {
      mpu.update();
    }
  }
  else if(desired_thrust<0) // i.e. fire the negative-moment thrusters
  {
    //start by setting the two unused thrusters to LOW
    digitalWrite(solenoid1_pin,LOW);
    //digitalWrite(solenoid3_pin,LOW);  // uncomment this when using four-thruster setup

    //implement pwm control logic for one period of thrusting
    digitalWrite(solenoid2_pin, HIGH);
    //digitalWrite(solenoid4_pin, HIGH);  // uncomment this when using four-thruster setup
    timer = millis();
    while(millis() - timer < openGap)
    {
      mpu.update();
    }



    digitalWrite(solenoid2_pin, LOW);
    //digitalWrite(solenoid4_pin, LOW);  // uncomment this when using four-thruster setup
    timer = millis();
    while(millis() - timer < closeGap)
    {
      mpu.update();
    }
  }
}
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
